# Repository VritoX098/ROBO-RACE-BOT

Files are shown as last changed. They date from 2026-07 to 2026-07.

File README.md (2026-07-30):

# 4WD ESP32 Bluetooh Robo Race bot 

A fully customizable 4-wheel drive robot controlled via bluetooh using an ESP-32 and L298N motor driver.

---

## Overview 

This project is a 4WD robot built aroubd the ESP32 microcontroller. It uses an L298N motor driver to control four TT/BO gear motors, powered by a 3S 18650 li-ion battery pack. The robot can be controlled wirelessly via bluetooh using any phone or computer with a serial terminal app.

The project was designed from the ground up. All design files, firmware and documentation are included in this repo to make it fully reproducible.

- Why I build this:  

I wanted to learn hardware design form scratch. This project forced me to understand every component in detail. 

---
| Robo race bot img-1 | Robo race bot img-2 |
| :---: | :---: |
|  |  |

---

## Project Demos
Head to:  [`Video/`](Video):

---

## Features 

- 4WD Drive System 
- Wireless Bluetooh Control 
- PWM speed control 
- Custom L298N PCB 
- 3D Printed Chassis 
- Rechargeable Battery 
- Open Source 

--- 

## Bill of materials 

ESP-32 - 1 pcs - Rs.1050 - [Esp32](https://www.daraz.com.np/products/esp32-development-board-i131400906.html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)  

L298N Motor Driver - 1 pcs - Rs.400 - [Driver](https://www.daraz.com.np/products/l298-motor-driver-module-i29709.html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)

BO motor - 4 pcs - Rs.400 - [Motor](https://www.daraz.com.np/products/dual-shaft-bo-motor-with-wheel-4-pcs-each-i127911357.html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)

BO motor wheel - 4 pcs - Rs. 400 - [Wheel](https://www.daraz.com.np/products/dual-shaft-bo-motor-with-wheel-4-pcs-each-i127911357.html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)

18650 Li-ion Battery - 3 pcs - Rs. 100*3 [Battery](https://www.daraz.com.np/products/37v-lithium-ion-rechargeable-battery-2000mah-icr-18650-i126733067.html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) 

3S battery holder - 1 pcs - Rs.165 - [Holder](https://www.daraz.com.np/products/3s-battery-holder-case-for-three-18650-lithium-ion-battery-i129213576.html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)

Switch - Rs.50 - [Switch](https://www.daraz.com.np/products/small-switch-i128943111.html?spm=a2a0e.searchlist.list.5.53d93c83h1LKsz)

Jumper Wires - Rs. 380 - [Jumper](https://www.daraz.com.np/products/40-pieces-male-to-female-dupont-jumper-wire-cable-20cm-two-point-five-four-millimeter-arduino-breadboard-electronics-connector-i129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)

PCB - 9$ 

Soldering Equipment - Rs.2000 - [Kit](https://www.daraz.com.np/products/soldering-iron-kit-15-in-1-60w-220v-adjustable-temperature-welding-tool-with-solder-tip-wire-desoldering-pump-tweezers-stripper-cut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)

Multimeter - Rs.350 - [Multimeter](https://www.daraz.com.np/products/digital-multimeter-lcd-ac-dc-measuring-voltage-current-for-home-use-campus-component-voltage-ampere-ohm-tester-electronic-tester-ye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)

Total - Rs. 5,500 ( 50$ )

---

## Build Instructions 

1. Mount BO Motors using hot glue gun
2. Attach its Wheels
3. Mount L298N motor driver with M3 screws 
4. Mount ESP-32 using double side tape
5. Install Battery holder with double side tape or zip ties
6. Wire Everything ( take guide from circuit or the code )
7. Final Checks with multimeter 
8. Upload code in esp32
9. Download an app called "Bluetooth RC Controller" from chrome
10. Connect your esp32 and control your bot 

---

## Build journals 

Development notes and progress logs are kept in [`Journals/`](Journals):

## Future Improvements 

- Can be made an obstacle avoiding bot using ultrasonic sensor
- Can be made a line following robot using IR sensors
- Add a camera module for FPV 
- Add battery voltage monitoring and low battery cutoff 
- Implement a mobile app for better UI control 

---

## Acknowledgements 

- Hack club macondo for the inspiration and guidance 
- PlatformIO for amazing development environment 
- KiCad for the free and powerful PCB design tools 
- All the open-source hardware communities for their invaluable resources 

---

## Esstenial links 

[Onshape](https://cad.onshape.com/documents/eafc86527aab621078fd5eab/w/5d8777175a4e24f0c6748078/e/ad99eee1d031578527ea4a44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)

[Cirkit Designer](https://app.cirkitdesigner.com/project/1adc6cdf-6aa5-4c88-b8ef-e48ef29de465)

---

For questions or feedback, open an issue on github or reach out on the hc slack.

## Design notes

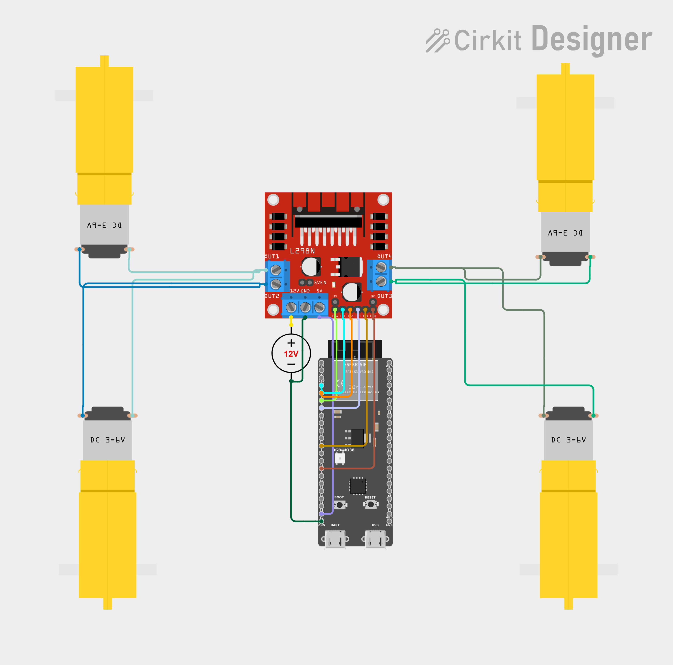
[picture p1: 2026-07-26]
CIRCUIT/circuit_image.png

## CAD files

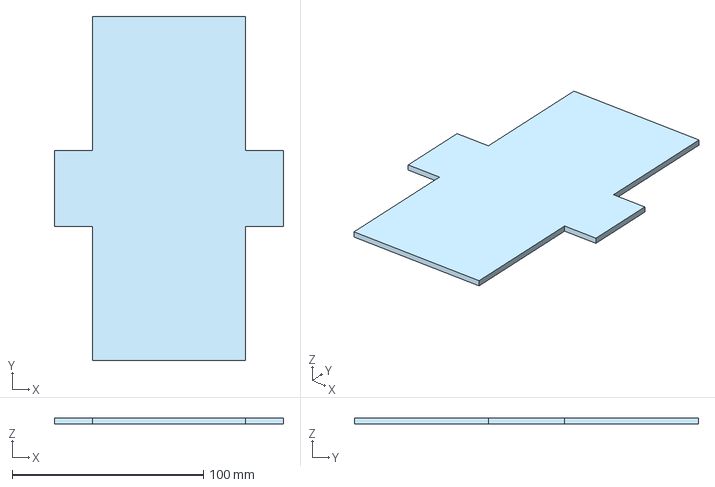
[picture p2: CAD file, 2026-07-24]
CAD/Chassis.step
120.0 x 180.0 x 3.00 mm

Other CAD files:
CAD/Chassis.stl

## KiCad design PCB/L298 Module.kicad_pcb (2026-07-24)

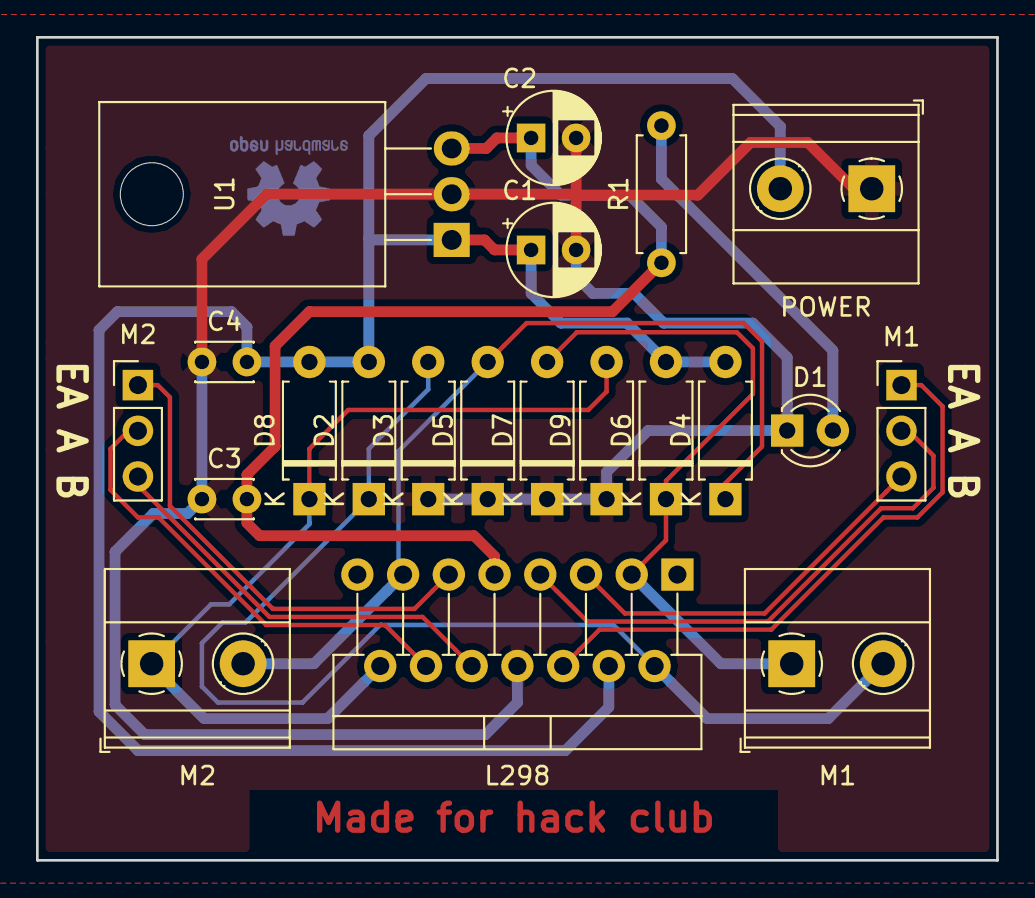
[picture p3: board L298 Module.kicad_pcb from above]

Board: 2 copper layers, 53.3 x 45.7 mm, 21 parts (0 on the bottom side), 14 nets.

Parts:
C1, C2: 47u; CP_Radial_D5.0mm_P2.50mm
C3, C4: 100n; C_Disc_D3.0mm_W2.0mm_P2.50mm
D1: LED; LED_D3.0mm
D2, D3, D4, D5, D6, D7, D8, D9: 1N4007; D_A-405_P7.62mm_Horizontal
L298: L298HN; TO-220-15_P2.54x2.54mm_StaggerOdd_Lead4.58mm_Vertical
M1: MOTOR1 IN; PinHeader_1x03_P2.54mm_Vertical
M1#2: MOTOR1 OUT; TerminalBlock_Phoenix_MKDS-1,5-2-5.08_1x02_P5.08mm_Horizont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
M2: MOTOR2 IN; PinHeader_1x03_P2.54mm_Vertical
M2#2: MOTOR2 OUT; TerminalBlock_Phoenix_MKDS-1,5-2-5.08_1x02_P5.08mm_Horizont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
POWER: POWER; TerminalBlock_Phoenix_MKDS-1,5-2-5.08_1x02_P5.08mm_Horizont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
R1: R; R_Axial_DIN0207_L6.3mm_D2.5mm_P7.62mm_Horizontal
U1: L7805; TO-220-3_Horizontal_TabDown

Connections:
+5V: C2.1, C3.2, L298.9, R1.1, U1.3
+BATT: C1.1, C4.2, D2.2, D4.2, D6.2, D8.2, L298.4, POWER.2, U1.1
GND: C1.2, C2.2, C3.1, C4.1, D1.1, D3.1, D5.1, D7.1, D9.1, L298.8, POWER.1, U1.2
unnamed: D1.2, R1.2
unnamed: D2.1, D3.2, L298.2, M1#2.2
unnamed: D4.1, D5.2, L298.13, M2#2.2
unnamed: D6.1, D7.2, L298.3, M1#2.1
unnamed: D8.1, D9.2, L298.14, M2#2.1
unnamed: L298.6, M1.1
unnamed: L298.7, M1.2
unnamed: L298.5, M1.3
unnamed: L298.11, M2.1
unnamed: L298.12, M2.2
unnamed: L298.10, M2.3

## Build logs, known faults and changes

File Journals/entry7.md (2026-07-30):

Wrote the initial code today to make the motors spin. This was actually not as bad as I expected cause I've been messing with Arduino code before.

Wrote a simple setup function with pinMode for all the GPIOs. Then a loop that spins the motors forward for 2 seconds, stops for 1 second, backward for 2 seconds, stops for 1 second. Super basic.

Uploaded the code to ESP32. Watched the serial monitor and it said "Motor Test Started" then nothing else. The motors didn't spin. I was so confused.

Debugging took forever. Checked the code multiple times its all correct. Checked the wiring again all correct. Then I realized the ESP32 wasn't getting 5V from the L298N. 

Then I tried using an external powwerbank to power esp32, and it worked but I can use it for the actual competition so I have to debug this and find some solution.

|  |  |
| :---: | :---: |
| |  |

The motors started spinning. The serial monitor showed all the print statements but one side of the motor was spinning but the other side wasn't, then I again checked the entire circuit.
All IN pins were connected properly, 12V from the battery to L298N, 5V from l298n to the esp32 and reuploaded the code. 

(https://cdn.hackclub.com/019fb0f0-99de-79b3-8b73-985a98d040cb/1000041824.mp4)  

(https://cdn.hackclub.com/019fb0f2-c770-76a5-bc04-3600e6d923b9/1000044374.mp4) |

But when it finally worked and I could control the robot from my phone? That was insane. The robot responds instantly with no lag. I was walking around my room steering it like an RC car.

Then I added advanced movement functions - moveForward(), moveBackward(), turnLeft(), turnRight(), stopMotor(). Each one takes a speed parameter for PWM control.

Also implemented a Bluetooth interface using the ESP32's built-in BLE. Downloaded a Serial Bluetooth Terminal app on my phone. Wrote a parser that reads incoming characters and maps them to movements. 'F' for forward, 'B' for backward, 'L' for left, 'R' for right, 'S' for stop. Speed can be adjusted with number keys 1-9.

The BLE code was the hardest part. The library kept throwing errors and I had to downgrade the ESP32 board package to version 2.0.14 or something. Took like an hour just to figure out the library compatibility issue.

The final robot: 

(https://cdn.hackclub.com/019fb0f5-d8d8-7616-8c10-8e039251e4d0/1000044375.mp4)

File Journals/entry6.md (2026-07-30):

Connected the ESP32 to the L298N today. This is where things got messy.

The initial wiring was a complete disaster cause I used too many jumper wires and it looked like spaghetti. I couldn't tell which wire was going where and ended up crossing a few connections. The motors wouldn't spin and I was lowkey panicking.

|  |  |
| :---: | :---: |
|  |  |

Spent like an hour just tracing wires and checking connections with the multimeter. Realized I swapped IN1 and IN2 on one side. Fixed that and the motors started spinning! But only in one direction?? Turns out I had soldered the wires of the motor wrong, now I have to resolder it.
 

After all that I organized the wiring and used some black tape to make it look less chaotic. Still messy but better.



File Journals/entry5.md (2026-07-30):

Today I Wired up the 3S 18650 battery holder. Those batteries are heavy af btw. 

This part was tricky cause the L298N needs 12V from the battery but the ESP32 needs 5V. The L298N has a built-in 5V regulator so I decided to use that to power the ESP32. Connected the battery + to L298N VCC, battery to L298N GND, then L298N 5V output to ESP32 VIN. Simple in theory but took me a while to figure out.

|  |  |
| :---: | :---: |
|  |  |

I had to add a switch between the battery and L298N cause I didn't wanna keep unplugging the battery every time. Soldered an on/off toggle switch inline with the positive wire. Works perfectly.

Tested the voltage with a multimeter and got 12.4V from the battery, 5.1V from the L298N regulator. Both in spec. No magic smoke released which is a good sign.

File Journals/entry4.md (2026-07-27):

I finally decided to build a 4WD ESP32 robot. Watched way too many tutorials today. My YouTube history is basically all "ESP32 robot tutorial" and "L298N motor driver explained". I'm a total beginner to hardware so most of it went over my head but I think I got the gist.

Components I'm using: ESP32 dev board, L298N motor driver, 4 BO motors with wheels, 3x 18650 batteries in a 3S holder. Also lots of jumper wires cause I know I'll mess up the connections.

gathered all the components, now its time to make chassis.

Although I have made 3d model of the chassis, I am going to cut ply wood because I don't have access to 3d printers. Cutting the ply was not an easy task. I broke few before finalizing the actual design.

 

Then I mounted the BO motors onto the chassis using hot glue gun.
The motors were brand new so I had to solder wires in them.
This took time because if I soldering the wrong size of the motor then 2 of my motor will rotates in one direction and other 2 in another direction so I had to be a bit careful there.



Attached the battery holder and it was now giving the vibe of actual robo car.

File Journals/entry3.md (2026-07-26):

**Journal Entry 3 - Circuit Simulation (Cirkit Designer)**

Okay so today I wanted to test if my circuit actually works before I solder everything together and potentially fry my ESP32. Found this website called Cirkit Designer that lets you simulate circuits and even run code on a virtual ESP32. Seemed too good to be true but I gave it a shot.

First attempt was a complete flop ngl. I picked some random ESP32 model from the component library without checking if it supports simulation. Uploaded my motor control code and nothing happened. The motors just sat there like 😐. Wasted like 30 minutes troubleshooting before realizing the model I selected literally can't be simulated. Rip. 

| Circuit Diagram | Cirkit Designer Simulation Warning |
| :---: | :---: |
| Circuit Diagram | Cirkit Designer Simulation Warning |

Started over and found the ESP32-S3 model which apparently works with the simulator. Swapped it out and re-did all my connections. This time when I uploaded the code something actually happened?? The virtual motors started spinning and I literally screamed.

|  |  |
| :---: | :---: |
|  |  |

---

I wrote some basic movement code - forward for 3 seconds, stop, backward for 3 seconds, stop. Just wanted to see if the L298N driver responds properly. And it worked?? The simulation showed the motors rotating in both directions and everything.

|  |  |
| :---: | :---: |
|  |  |

---

The L298N part was kinda finicky though. Had to play around with the PWM values cause the motor speed was either 0 or 100 with nothing in between at first. Messed with the frequency settings and eventually got it working smooth.

|  |  |
| :---: | :---: |
|  |  |

---

|  |  |  |
| :---: | :---: | :---: |
|  |  |  |

Now I'm confident enough to start assembling the real thing tomorrow. Lowkey nervous but ready to lock in.

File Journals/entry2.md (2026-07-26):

**Journal Entry 2 - CAD Design (Onshape)**

okay so moved on to the mechanical side today. started designing the chassis in Onshape. the goal is to make a simple 4WD chassis that can hold all the components and look kinda clean. I will be making the chassis of my bot using ply wood available locally but for the submission requirements I am making this and also to see how it goes...

---

I sketched out a basic rectangle with cutouts for the wheels. it's not pretty but it'll work lmao. I need to measure the motor dimensions properly tho because rn I'm kinda guessing and that's gonna come back to bite me later.



---
I also started thinking about the CAD assembly of the whole bot. like I want to have the motors, driver, ESP32, and battery all in one 3D model so reviewers can see how everything fits together.



---



---



---



---

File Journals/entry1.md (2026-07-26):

**Journal Entry 1 - PCB Design (KiCad)**

ok so today I finally started my 4WD robot project for macondo. ngl I was lowkey stressing about where to even begin but I just decided to jump in and figure it out as I go 

I started with the PCB design in KiCad for the L298N motor driver. I know I could just buy one off the shelf but I need to show some actual PCB work for the submission.

so I spent like an hour just watching tutorials because I haven't touched KiCad in months tbh.

- started the schematic, divided it into two main sections like the guide said: power and motor driver

- added the 7805 voltage regulator for the 5V logic supply. guide says input should be 7-12V, but i'm gonna use the 3S battery pack (around 11.1V) so it should be fine

- placed the L298 IC and connected all the pins. ngl, the datasheet was confusing at first but i got there

- added the flyback diodes for back EMF protection (1N4007 ones, cheap and readily available)

- put in the filter capacitors (100µF and 0.1µF) for both motor and logic power inputs

- added a power LED so i know when the board is on. saves debugging headaches later.

---



---


honestly, this is taking longer than i thought. the guide makes it look easy but component placement and routing is a whole different beast.

the power traces are thick af now like 1.5mm for the motor supply. dont want any voltage drop when the motors are pulling current. the signal traces are thinner cuz they just carry logic signals to the l298.

i ran into some issues with the ground plane though. the guide mentions having a solid ground plane but i kept getting drc errors when i tried to pour copper. turns out i had to change some settings in kicad for the clearance. eventually got it working after watching a quick youtube tutorial lol.

added mounting holes on the corners of the pcb like i planned. used 3mm holes so i can screw it down with standoffs. also added some test points on important signals just in case i need to debug later.

heres a pic of the final pcb render:

---


---



---



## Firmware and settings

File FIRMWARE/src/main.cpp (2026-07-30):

#include <BluetoothSerial.h>
#include <Arduino.h>

const int IN1 = 13;
const int IN2 = 12;
const int IN3 = 14;
const int IN4 = 27;
const int ENA = 25;
const int ENB = 26;

BluetoothSerial SerialBT;
int motorSpeed = 180;
bool isMoving = false;

void moveForward(int speed);
void moveBackward(int speed);
void turnLeft(int speed);
void turnRight(int speed);
void stopMotors();
void setMotorSpeed(int leftPwm, int rightPwm);
void handleBluetoothCommand(char cmd);

void setup() {
  Serial.begin(115200);
  Serial.println("4WD Robot starting...");

  pinMode(IN1, OUTPUT);
  pinMode(IN2, OUTPUT);
  pinMode(IN3, OUTPUT);
  pinMode(IN4, OUTPUT);
  pinMode(ENA, OUTPUT);
  pinMode(ENB, OUTPUT);

  SerialBT.begin("ESP32_Robot");
  Serial.println("Bluetooth ready. Pair with 'ESP32_Robot'");

  stopMotors();
}

void loop() {
  if (SerialBT.available()) {
    char cmd = SerialBT.read();
    if (cmd == '\n' || cmd == '\r') return;
    handleBluetoothCommand(cmd);
    Serial.print("Command received: ");
    Serial.println(cmd);
  }
  delay(10);
}

void setMotorSpeed(int leftPwm, int rightPwm) {
  leftPwm = constrain(leftPwm, 0, 255);
  rightPwm = constrain(rightPwm, 0, 255);
  analogWrite(ENA, leftPwm);
  analogWrite(ENB, rightPwm);
}

void moveForward(int speed) {
  digitalWrite(IN1, HIGH);
  digitalWrite(IN2, LOW);
  digitalWrite(IN3, HIGH);
  digitalWrite(IN4, LOW);
  setMotorSpeed(speed, speed);
  isMoving = true;
}

void moveBackward(int speed) {
  digitalWrite(IN1, LOW);
  digitalWrite(IN2, HIGH);
  digitalWrite(IN3, LOW);
  digitalWrite(IN4, HIGH);
  setMotorSpeed(speed, speed);
  isMoving = true;
}

void turnLeft(int speed) {
  digitalWrite(IN1, LOW);
  digitalWrite(IN2, HIGH);
  digitalWrite(IN3, HIGH);
  digitalWrite(IN4, LOW);
  setMotorSpeed(speed, speed);
  isMoving = true;
}

void turnRight(int speed) {
  digitalWrite(IN1, HIGH);
  digitalWrite(IN2, LOW);
  digitalWrite(IN3, LOW);
  digitalWrite(IN4, HIGH);
  setMotorSpeed(speed, speed);
  isMoving = true;
}

void stopMotors() {
  digitalWrite(IN1, LOW);
  digitalWrite(IN2, LOW);
  digitalWrite(IN3, LOW);
  digitalWrite(IN4, LOW);
  analogWrite(ENA, 0);
  analogWrite(ENB, 0);
  isMoving = false;
}

void handleBluetoothCommand(char cmd) {
  if (cmd >= '0' && cmd <= '9') {
    int newSpeed = map(cmd - '0', 0, 9, 0, 230);
    motorSpeed = newSpeed;
    Serial.print("Speed set to: ");
    Serial.println(motorSpeed);
    return;
  }

  switch (cmd) {
    case 'F':
      moveForward(motorSpeed);
      break;
    case 'B':
      moveBackward(motorSpeed);
      break;
    case 'L':
      turnLeft(motorSpeed);
      break;
    case 'R':
      turnRight(motorSpeed);
      break;
    case 'S':
      stopMotors();
      break;
    default:
      Serial.println("Unknown command");
      break;
  }
}

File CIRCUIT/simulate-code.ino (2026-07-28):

#define ENA 6
#define IN1 4
#define IN2 5

#define ENB 9
#define IN3 7
#define IN4 8

void setup() {
  pinMode(ENA, OUTPUT);
  pinMode(IN1, OUTPUT);
  pinMode(IN2, OUTPUT);

  pinMode(ENB, OUTPUT);
  pinMode(IN3, OUTPUT);
  pinMode(IN4, OUTPUT);

  // Full speed
  analogWrite(ENA, 255);
  analogWrite(ENB, 255);
}

void loop() {
  forward();
  delay(3000);

  stopMotors();
  delay(1000);

  backward();
  delay(3000);

  stopMotors();
  delay(1000);
}

void forward() {
  digitalWrite(IN1, HIGH);
  digitalWrite(IN2, LOW);

  digitalWrite(IN3, HIGH);
  digitalWrite(IN4, LOW);
}

void backward() {
  digitalWrite(IN1, LOW);
  digitalWrite(IN2, HIGH);

  digitalWrite(IN3, LOW);
  digitalWrite(IN4, HIGH);
}

void left() {
  digitalWrite(IN1, LOW);
  digitalWrite(IN2, HIGH);

  digitalWrite(IN3, HIGH);
  digitalWrite(IN4, LOW);
}

void right() {
  digitalWrite(IN1, HIGH);
  digitalWrite(IN2, LOW);

  digitalWrite(IN3, LOW);
  digitalWrite(IN4, HIGH);
}

void stopMotors() {
  digitalWrite(IN1, LOW);
  digitalWrite(IN2, LOW);

  digitalWrite(IN3, LOW);
  digitalWrite(IN4, LOW);
}

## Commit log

2026-07-24 l298n motor driver module pcb
    [L298 Module.kicad_pcb, L298 Module.kicad_sch]
2026-07-24 CAD files of the chassis and assembly of the bot
    [Chassis.step, Chassis.stl]
2026-07-26 Update Journal Entry 1 with PCB design details
    Documented progress on PCB design for 4WD robot project, including schematic creation, component placement, and troubleshooting.
2026-07-26 Add Journal Entry 2 for CAD design progress
    Documented progress on CAD design for a 4WD chassis in Onshape, including sketches and assembly considerations.
2026-07-26 Add Journal Entry 3 on Circuit Simulation
    Documented the process of simulating a circuit using Cirkit Designer, including troubleshooting and successful motor control tests.
2026-07-26 Circuit design made using circkit designer
2026-07-27 Add journal entry for building 4WD ESP32 robot
    Documented the process of building a 4WD ESP32 robot, including components used and challenges faced while constructing the chassis and mounting motors.
2026-07-28 Add motor control functions for simulation
2026-07-30 Add platformio.ini for ESP32 development
2026-07-30 Add Bluetooth control for 4WD robot motors
2026-07-30 Add project overview and documentation to README
    Added detailed project description, features, bill of materials, build instructions, future improvements, and acknowledgements.
2026-07-30 Add journal entry for wiring battery and L298N
    Documented the wiring setup for the 3S 18650 battery holder and the L298N motor driver, including voltage testing results.
2026-07-30 Add journal entry for ESP32 and L298N connection
    Documented the process of connecting the ESP32 to the L298N, including wiring challenges and troubleshooting steps.
2026-07-30 Add journal entry for robot motor control project
    Documented the process of coding and debugging motor control for a robot using ESP32. Included details about the setup, issues faced, and final implementation with Bluetooth control.
2026-07-30 Update README with PCB cost and essential links
    Added PCB and essential links sections to the README.
2026-07-30 Added gerber file
    [L298 Module-B_Cu.gbr, L298 Module-B_Mask.gbr, L298 Module-B_Paste.gbr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]
